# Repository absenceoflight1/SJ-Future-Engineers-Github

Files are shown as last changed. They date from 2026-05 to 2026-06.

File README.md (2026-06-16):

# SJ-Future-Engineers

Welcome to the GitHub Repository of Team Robosenian, competing for the Philippine Robotics Olympiad Future Engineers 2026. The robot is an autonomous, scaled-down vehicle designed to navigate a structured track, avoid obstacles (red and green pillars), and park or change lanes based on visual feedback. The architecture decouples high-level computer vision and path planning from low-level motor actuation and sensor data aggregation.

The autonomous vehicle uses a single SPIKE Prime Large Hub as both the high-level logic controller and low-level actuator driver. The robot navigates an obstacle course using color detection and ultrasonic distance mapping, processing all feedback locally on the hub using the Pybricks.

Steering Mechanism (Ackermann Geometry)
Instead of differential drive (like a tank), the vehicle utilizes Ackermann steering geometry. This ensures that when the robot turns, all wheels trace concentric circles around a single common center point, preventing the tires from slipping sideways.
Actuation: A single spike prime motor is linked to the front steering knuckles via adjustable turnbuckles.
Mechanical Advantage: The steering linkages are configured so that the inner wheel turns at a sharper angle than the outbound wheel during a turn.
Propulsion: A single SPIKE Large Motor drives the rear axle.
Color Sensors: Mounted low to the ground, pointing down at the front to recognize boundary lines (blue/orange), or angled forward to evaluate the color signatures of obstacle pillars (red/green). 
Ultrasonic Sensor: Mounted to the side and front to identify track outer walls or confirm distance to a pillar.

# Members 
-**<p>Ethan Blaire S. De la Piña</p>** 
*<p>Background: Student of San Jose National High School</p>*
<p>Role: Coder, Strategist</p>
Year of Birth: 2009

-**<p>Jay Arnel A. Garcia</p>**
*<p>Background: Student of San Jose National High School</p>*
Role: 3D Printer, Documentator
<p>Year of Birth: 2010</p>

-**<p>Mel Iven M. Pangandoyon</p>**
*<p>Background: Student of San Jose National High School</p>*
Role: Build Designer, Coder
<p>Year of Birth: 2009</p>

-**<p>Nelson T. Ingking</p>**
*<p>Background: Teacher in San Jose National High School</p>*
Role: Team Coach, Guide
<p>Year of Birth: 1985</p>

# Strategies

The strategy we implemented for Open Challenge is that, after the color sensor first detects whether it is orange or blue, it accelerates based on the direction it is moving. For the Obstacle Challenge, our strategy is that after the color sensor detects a line, whether orange or blue, the robot maneuvers itself into the direction it will run, parallel to the wall.

### Mobility Management 

Mobility management governs how our vehicle physically moves, translates software decisions into mechanical force, and maintains structural stability on the track. Our architecture decouples traction control (propulsion) from directional control (steering) to optimize efficiency, torque, and tracking accuracy.
<p>A. Propulsion System (The Drive Motor)Component Selected: SPIKE Large Motor (drive = Motor(Port.C))</p>
<p>Implementation: Mounted longitudinally at the rear of the vehicle, driving the rear axle directly.</p>
<p>Engineering Principles (Torque vs. Speed): The propulsion system requires high starting torque to overcome static friction and rapidly accelerate out of corner turns. The Large Motor provides a superior stall torque (continuous, peaking higher under duty cycle) compared to smaller variants. Because our script commands the motor using raw duty cycle percentages (drive.dc(DCSPEED)), the motor naturally draws more current to provide the necessary torque when encountering resistance, maintaining steady momentum without stalling.</p>
<p>B. Directional Control (The Steering Actuator)Component Selected: SPIKE Medium Servo Motor (steer = Motor(Port.A))</p>
Implementation: Positioned at the front of the vehicle, directly over the front axle assembly.</p>
<p>Engineering Principles (Precision & Speed): Steering requires high rotational speed and precise angular positioning rather than high continuous torque. The Medium Servo features a lower internal gear ratio, allowing it to snap to exact targeted angles (steer.run_target(1000, angle)) at speeds up to 1000 deg/s.</p>
<p>Internal PID Feedback: Both motors utilize embedded optical encoders that track positions with 1 degree resolution. This allows the Pybricks firmware to run internal Proportional-Integral-Derivative (PID) loops, ensuring the steering angles match our software's structural variables precisely, even under the lateral stress of a turn.</p>
Vehicle Chassis Design and Geometry. The foundation of our mobility management relies on Ackermann Steering Geometry rather than a differential (tank-style) drive.</p>

**<p>3D PRINTED FILES</p>**
[BASE](models/FE_NEW_BASE.stl)
[L HOLDER](models/NEW_FE_LHOLDERR.stl)
[COVER](models/cover.stl)
[ULTRASONICHOLDER](models/newsonicholder.stl)
### Power and Sense Management

<p>Power and sense management dictate how our vehicle distributes electrical energy to sustain high-performance operations and how it gathers environmental telemetry to safely solve the track challenges. This subsystem ensures that our computational nodes, sensors, and actuators are adequately powered without experiencing voltage drops or signal degradation.</p>

**<p>A. Primary Power: LEGO SPIKE Prime Battery</p>**
<p><strong>Specifications: 7.3V, 21000 mAh</strong>Lithium-Ion rechargeable battery pack housed inside the SPIKE Prime Hub.</p>
<p><strong>Allocation:</strong>Powers the central ARM Cortex-M7 processor, the internal 6-axis IMU, the front steering servo motor, the rear drive motor, the downward color sensor, and the ultrasonic sensor.</p>
<p><strong>Engineering Justification:</strong>The drive motor experiences heavy spikes in inductive current draw during acceleration and rapid reversals. By keeping this high-current draw on its own isolated chemical cell, we eliminate the risk of voltage sags (brownouts) that would reset our microcontrollers.</p>

**<p>B. Secondary Power: Vinko Mini Fast-Charging Power Bank</p>**
<p><strong>Specifications: 10000mAh (or 20000mAh)</strong>capacity featuring built-in smart LED capacity tracking and an integrated Type-C braided cable delivering up to <strong>22.5W max</strong> output power.</p>
<p><strong>Allocation:</strong> Dedicated solely to powering our co-processing vision subsystem: the ESP32 microcontroller and the DFRobot HuskyLens AI camera.</p>

### Open Challenge
Objective: Complete three autonomous laps.

The first problem we experienced was the random internal wall placements. The solution we implemented is that we put ultrasonics on both sides(left and right) of the robot. Another problem was the inconsistent reading of the color sensor. The solution we made was to make sure the sensor's physical environment is stable and maintain a consistent height. The last problem we encountered was that sometimes the build would fall off on its own. The solution for that was to balance the weight distribution of the robot.

### Open Management
Open Challenge management governs how our vehicle navigates a completely clear, obstacle-free track. In this mode, the primary objective is maximizing speed, minimizing lap times, and executing mathematically perfect 90° turns. The strategy focuses heavily on deep sensor synchronization, using the ground color sensor to locate boundary lines and the internal Inertial Measurement Unit (IMU) to lock down straight trajectories.

**Straight-Line Navigation (PD Gyro Control)**
<p>To prevent the vehicle from drifting into track walls over long straightaways, we implemented a Proportional-Derivative (PD) Gyro Control loop inside the do_gyro() function.</p>
<p>The vehicle constantly calculates its heading error by comparing its current absolute compass heading against our software's directional target variable (target).</p>

```python
err  = hub.imu.heading() - target
rate = hub.imu.angular_velocity()[2]
cor  = max(-STEER_LIMIT, min(STEER_LIMIT, KP * err - KR * rate))
steer.run_target(1000, int(STEER_CENTER + cor), wait=False)

```

<p>Proportional Control (KP * err): Quantifies how far off course the vehicle has drifted. We set KP to 3.0, meaning if the car drifts 5° to the left, the steering servo instantly counters by turning the front wheels 15° to the right.</p>

<p>Derivative Control (KR * rate): Measures the vehicle's rotational velocity (how fast it is spinning). We set KR to 0.2. This acts as an automated shock absorber, dampening the steering adjustments as the car approaches its straight heading to prevent erratic fish-tailing or over-correction.</p>

<p>Saturation Guarding: The final correction factor (cor) is bound tightly by STEER_LIMIT (80°) to prevent the code from forcing the motor past its physical end-stops.</p>

**Automated Cornering Strategy (The Race Line)**
<p>The vehicle tracks its progress around the course by using its downward-facing color sensor to recognize bright boundary lines taped to the track floor. When a line is crossed, the car executes a multi-stage turning matrix:</p>

*<p>Stage 1: Line Verification and Race Calibration</p>*
<p>The ground sensor reads the floor data. The functions is_blue() and is_orange() monitor Hue, Saturation, Value, and Reflection simultaneously. Once a line is confirmed, the vehicle ignores all subsequent color changes for a set duration (COOLDOWN_MS = 10000) to guarantee that the same physical line isn't counted twice.</p>

*<p>Stage 2: Frontal Distance Cushioning</p>*
<p>Upon registering a line, the vehicle does not turn immediately. It triggers wait_for_wall(), maintaining its straight gyro line at a controlled DCSPEED (50%) until the front ultrasonic sensor confirms that the vehicle is within 100 mm(WALL_TURN_MM) of the corner wall. This ensures the vehicle maximizes its deep entry into the corner before breaking away.</p>

*<p>Stage 3: Gyro Target Re-mapping</p>
<p>Once the spatial cushion is met, the code modifies our global absolute reference frame by precisely 90°:</p>

```python
if tdir == 'blue':
    target -= 90      # Adjust heading target for a sharp Left Turn
    direction = 1
else:
    target += 90      # Adjust heading target for a sharp Right Turn
    direction = 2

```

*<p>Stage 4: High-Torque Pivot Reversal</p>
<p>The vehicle cranks its front steering servo completely to its outer edge (TURN_STEER = 80). The main loop is temporarily suspended, and the rear drive motor runs in high-velocity reverse power (drive.run(-600)).</p>
<p>The vehicle swings its rear end around, pivoting into the corner. The internal IMU samples the rotation at a hardware level. The moment the gyro sensor registers that the vehicle's body has aligned within a tight 5° tolerance window (GYRO_ALIGN_TOL) of our new target heading, the reverse power cuts out, the steering assembly straightens back to 0°, </p>

### Obstacle Challenge 
Objective: Complete three laps with a traffic sign aligned with its direction.

The first problem we experienced was fixing the traffic sign compliance. The solution for that was to put a Husky Lens Camera that can be connected to an LMS. The second was the inconsistent detection of traffic lights from the camera. The solution was to put the camera at the back for a wider field of view. We also implemented a gyro for precise straight movement, maintaining angular velocity, and allowing a robot to track its rotation.

### Obstacle Management

Obstacle management defines how our vehicle identifies, evaluates, and evades hazards on the track in real time. For SJ-Future-Engineers, this system is divided into two distinct protective layers: Computer Vision Pillar Evasion (high-level path modifications handled via the camera) and the Ultrasonic Collision Buffer (low-level emergency braking handled via acoustic ranging).

High-Level Obstacle Evasion (The AI Vision Pipeline)
The primary tool for managing colored pillars (red and green blocks) is our machine learning co-processing subsystem, which is the LMS.

<p>A. Target Classification and Filtering.</p> 
<p>The HuskyLens camera constantly streams a 6-integer telemetry array to the SPIKE Prime Hub. The hub instantly processes these variables through a series of logical validation steps:</p>
<p>Color Identification: The function classify_block() translates the camera's raw signature ID (cid) into descriptive 'green' or 'red' text strings.</p>
<p>Dual-Target Arbitration: If both a red and a green pillar appear in the frame simultaneously, the main execution loop compares their bounding-box widths (green_w and red_w). The program prioritizes whichever block has the larger width, as a wider pixel profile indicates it is physically closer and poses the immediate structural threat.</p>
<p>Lock Acquisition: Once a dominant block is identified within a critical distance boundary (block_y > 50), the system triggers a software lock (locked_block). This lock prevents the car from switching target strategies midway through a turn if a second color flashes into view.</p>
<p>B. Spatial Zoning Matrices</p>
<p>The script partitions the camera’s 320 x 240 pixel viewing window into a coordinate grid to evaluate threats:</p>
<p>The X-Axis (Horizontal Positioning): Evaluated by classify_block_x(). It maps where the obstacle sits relative to our centerline.</p>
<p>The Y-Axis (Proximity Depth): Evaluated by classify_block_y(). A value of cy > 50 indicates the vehicle has breached the safe approach threshold.</p>
<p>The Width Profile (Size Verification): Evaluated by classify_block_width(). A pixel width value of cw >=11 triggers an "emergency" classification, proving the object is an actual roadblock and not a distant background color glitch.</p>

**<p>C. Evasion Trajectory Execution</p>**
<p>When detect_block() reports that a block is "near" and its size is an "emergency", the vehicle breaks away from its straight gyro line and enters the turn_to_ok() evasion routing:</p>

```python
if block_color == 'green':
    ok_zone    = 'g_kinda_ok'  # Safe escape corridor (cx: 64-128)
    wiggle_dir = 25            # Hard steer right
else:
    ok_zone    = 'r_kinda_ok'  # Safe escape corridor (cx: 64-128)
    wiggle_dir = -25           # Hard steer left

```
The vehicle suspends its standard gyro tracking algorithm and turns its steering knuckles exactly $25^\circ$ in the opposite direction of the block's identity—steering right to clear green pillars and steering **left to clear red pillars**.
<p>The car maintains this evasive curve until the camera feed updates and confirms that the block's horizontal coordinate (bx) has shifted completely into the safe peripheral flank zone (ok_zone). Once cleared, the wheel center, old tracking flags reset, and the background gyro control takes back control of straight-line navigation.</p>

**<p>3.3 Low-Level Collision Buffering (The Ultrasonic Safety Net)</p>**
<p>If an obstacle is missed by the camera (due to extreme glare, dark shadows, or an unlearned color profile), or if the vehicle approaches a solid track wall head-on, our low-level sensor array takes over.</p>
<p>The front-facing ultrasonic sensor (ultra) acts as an automated safety brake. It measures the physical distance to objects directly ahead by bouncing high-frequency sound waves off surfaces.</p>

```python 
if brake_on and df < ULTRA_FRONT_MM:
    emergency_reverse()

```
                     
<p>If the distance to a solid surface drops below 50 mm (ULTRA_FRONT_MM), the program stops processing normal track loops and fires emergency_reverse(). This routine drops the propulsion system into reverse power (-600) and backs up for exactly 1000 ms while centering the steering mechanism. This creates a spatial cushion, allowing the vehicle to reset its orientation and avoid an impact that could damage its front chassis or steering linkage geometry.</p>

# Modules

pybricks.hubs (PrimeHub): The core library for the main vehicle controller. It manages internal electronics like the 6-axis Inertial Measurement Unit (IMU/Gyro), built-in speaker, status LED matrix, and battery management.

pybricks.pupdevices (Motor, ColorSensor, UltrasonicSensor): The hardware abstraction layer for LEGO Powered Up (PUP) peripherals. It contains built-in feedback control systems (PID loops), allowing the code to command precise angles, tracking speeds, and distances.

pybricks.parameters (Color, Port): A configuration module containing constants that define the physical layout of the hub (e.g., ports A through E) and primitive colors for the LED light.

pybricks.tools (wait, StopWatch): The time-management module. wait() yields CPU control for safe scheduling, while StopWatch() implements software timers used heavily in your code for cooldowns and emergency reverse durations.

pupremote_hub (PUPRemoteHub): A communication protocol module. It enables the LEGO Hub to communicate via UART serial communication over a standard sensor port to an external microcontroller (in your case, an ESP32 running a HuskyLens AI camera).
### Electromechanical Hardware Mapping

| Component Instance | Physical Hardware Component | Vehicle Subsystem | Software Interaction & Functionality |
| :--- | :--- | :--- | :--- |
| **`hub = PrimeHub()`** | LEGO SPIKE Prime Brick / Hub | Central Controller & IMU | Processing unit. Uses internal **6-axis Gyro** via `hub.imu.heading()` to keep the vehicle straight. Controls built-in status lights and speaker beeps. |
| **`steer = Motor(Port.A)`** | LEGO Powered Up Servo Motor | Steering Actuator | Connected to front wheels. Uses internal optical encoders to turn wheels to exact structural angles (`STEER_CENTER`, `SIDE_WALL_NUDGE_STEER`). |
| **`drive = Motor(Port.C)`** | LEGO Powered Up Large Motor | Propulsion System | Connected to drive axles. Commanded via direct motor power duty-cycles (`drive.dc(DCSPEED)`) or regulated velocity track speeds (`drive.run()`). |
| **`color = ColorSensor(Port.E)`** | LEGO Color Sensor | Downward Lap Sensor | Pointed at track floor. Measures Hue, Saturation, Value, and raw reflection variables to flag down-track Blue/Orange boundary lap lines. |
| **`ultra = UltrasonicSensor(Port.D)`** | LEGO Ultrasonic Distance Sensor | Front Collision Buffer | Emits acoustic sound waves straight ahead. Evaluates buffer zone distance (`front_dist()`). Triggers emergency braking routines if wall distance drops below 50mm. |
| **`lms = PUPRemoteHub(Port.B)`** | ESP32 MCU + HuskyLens AI Camera | Vision & Side-Telemetry | Communicates via a serial UART bridge. Translates object bounding boxes (`cx`, `cy`, `cw`) and side-wall ToF sensor distances into raw system data arrays. |

### The Process to Build, Compile, and Upload the Code

We ensure that our LEGO Prime Hub has the  Pybricks Firmware installed. We have a Pybricks Code installed on our laptops. With this, we can now upload our code to the SPIKE Prime Hub and have the robot complete the open and obstacle challenges. When we click the green Play icon inside the Pybricks IDE, the deployment pipeline executes an automated process instantly. First, the browser IDE handles syntactic verification by parsing our code to catch structural Python syntax errors or unmapped variables before deployment. Next, bytecode compilation takes over to instantly compress the raw MicroPython script into an optimized, lightweight binary representation called a .mpy file. Finally, a stream upload sends this compiled bytecode directly over our active Bluetooth Low Energy or USB-C connection into the volatile RAM of the LEGO Prime Hub controller, initializing the vehicle for immediate execution.

# Pictures -Team and vehicle 

### Team Photos

**<p>Fun Photo</p>**

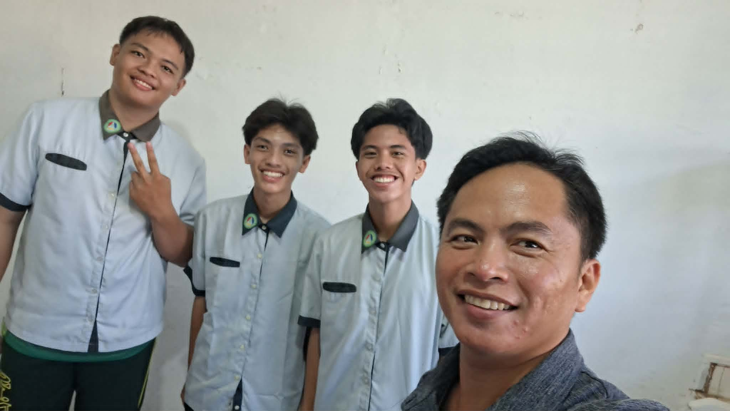
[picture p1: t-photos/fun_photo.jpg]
Fun Photo


**<p>Team Photo</p>**

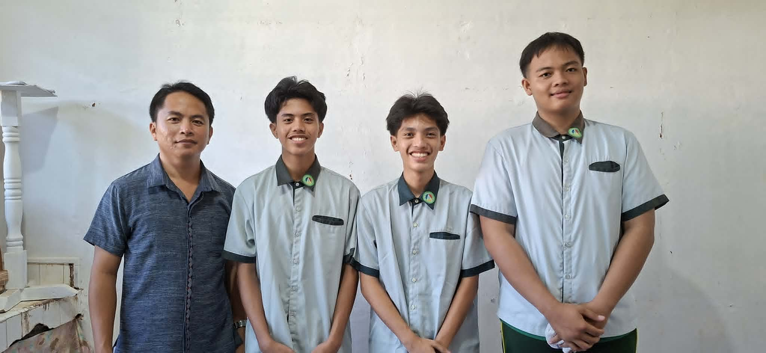
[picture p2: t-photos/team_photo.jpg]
Team Photo


<p>Official Team Photo</p>

### Vehicle Photos

**<p>Bottom View</p>**

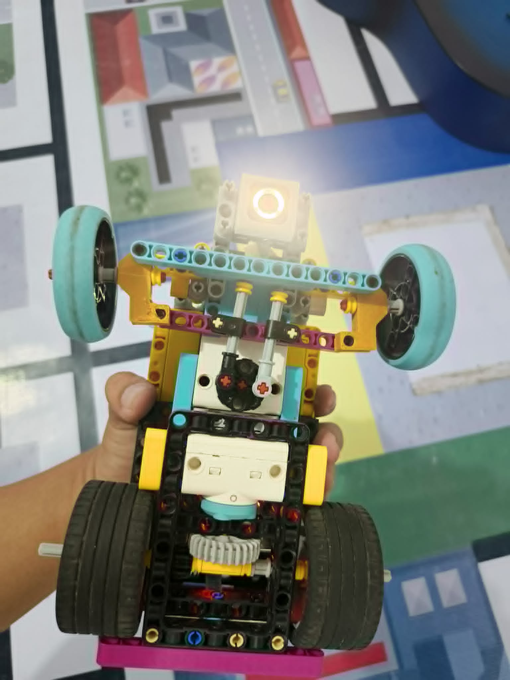
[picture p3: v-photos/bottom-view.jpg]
Bottom View


**<p>Front View</p>**

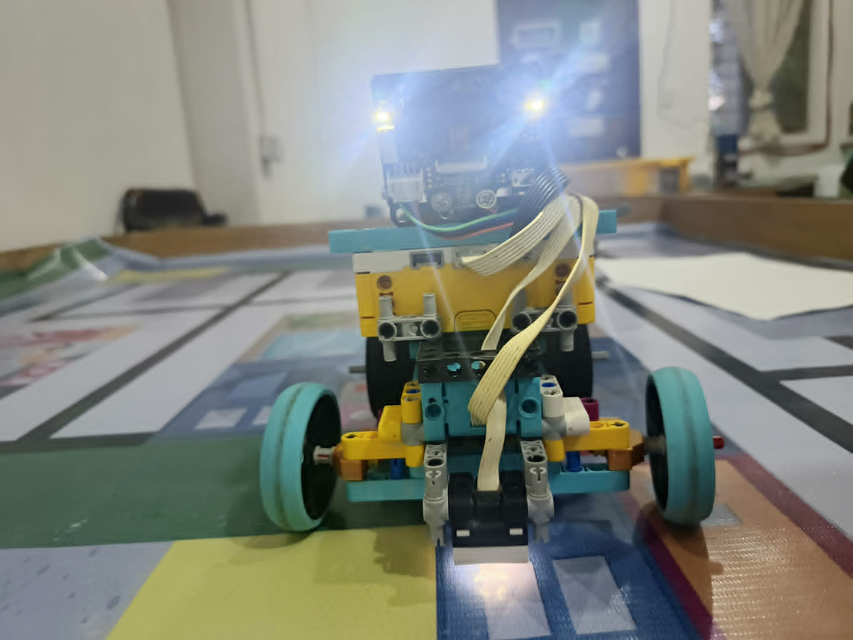
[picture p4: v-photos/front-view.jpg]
Front View


**<p>Left View</p>**

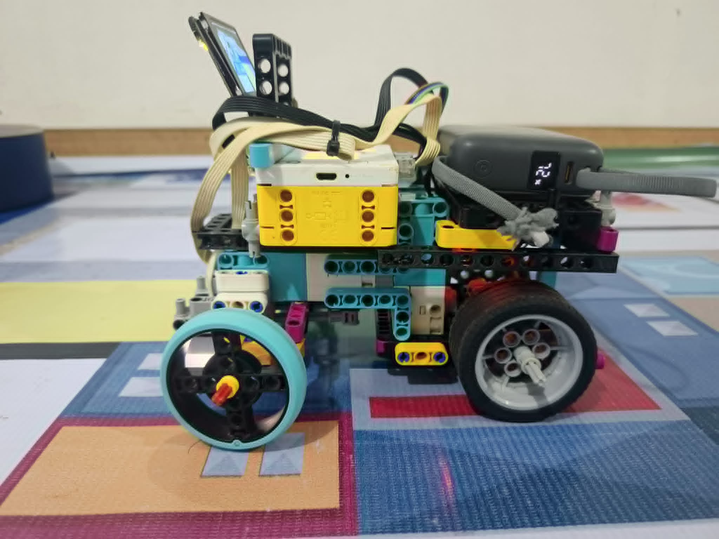
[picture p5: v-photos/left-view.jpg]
Left View


**<p>Rear View</p>**

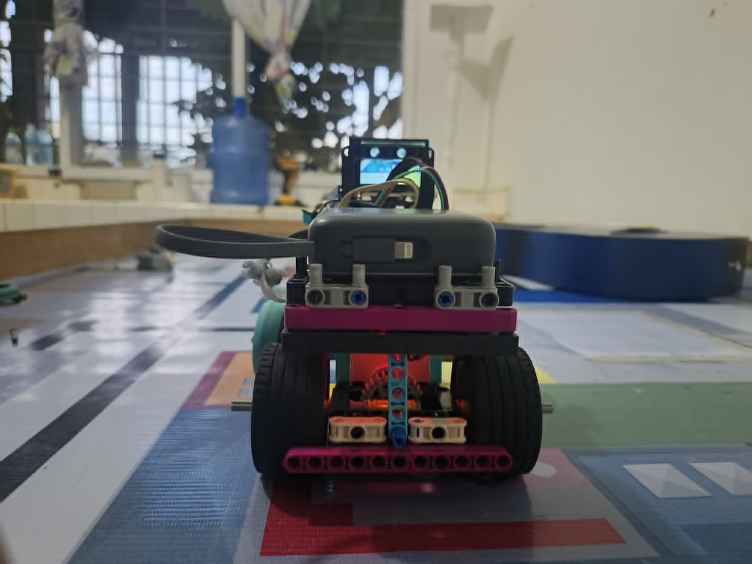
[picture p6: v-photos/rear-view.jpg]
Rear View


**<p>Right View</p>**

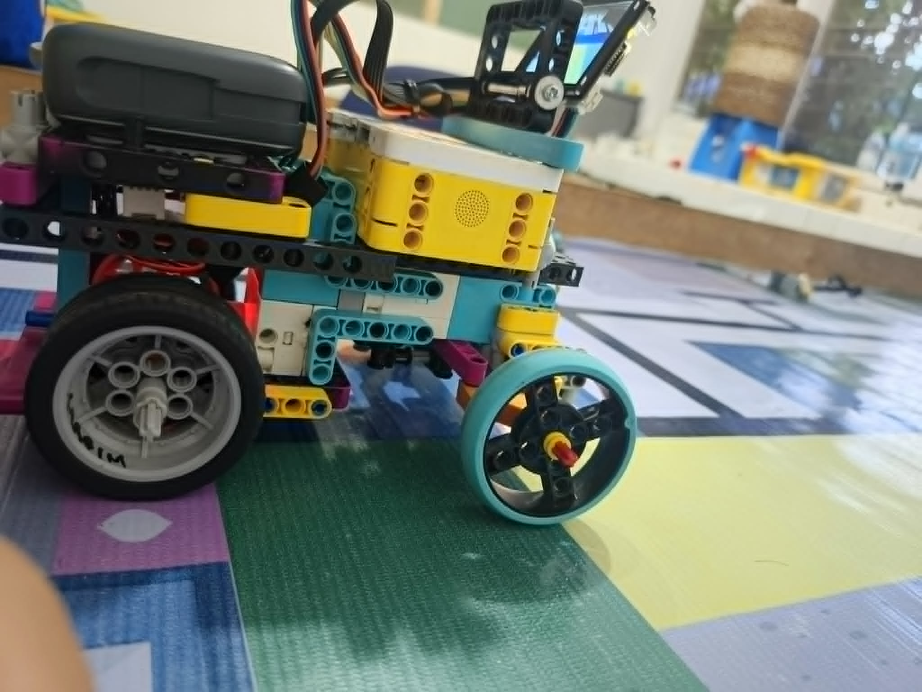
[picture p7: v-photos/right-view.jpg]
Right View


**<p>Top View</p>**

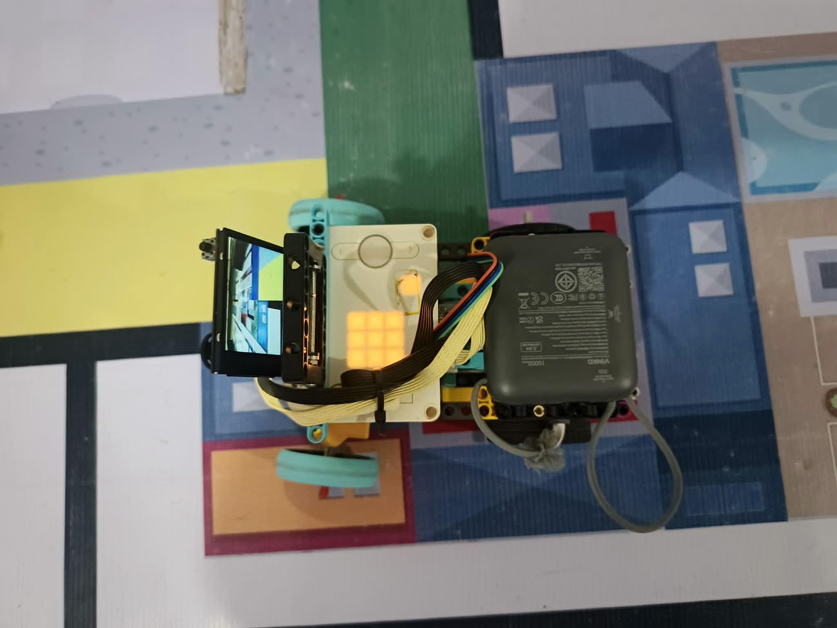
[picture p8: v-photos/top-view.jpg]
Top View


More description on 't-photos' subfolder.

# Video

**<p>Videos</p>**

Open Challenge Video (https://youtu.be/iB-URkR1FVM)

<a href="https://www.youtube.com/watch?v=iB-URkR1FVM">Youtube Link</a>

-<strong>Obstacle Challenge</strong>
    Obstacle Challenge Video (https://youtu.be/drb0f370XIs)

<a href="https://www.youtube.com/watch?v=drb0f370XIs">Youtube Link</a>

YouTube links are accessible. For more information, please look at the video subfolder.

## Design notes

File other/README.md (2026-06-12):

# Materials Used

<strong>LMS</strong>
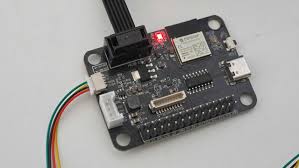
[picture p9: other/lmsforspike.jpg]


We used LMS to connect the Servo Motor and Husky Lens Camera to SPIKE.

<strong>Husky Lens Camera</strong>
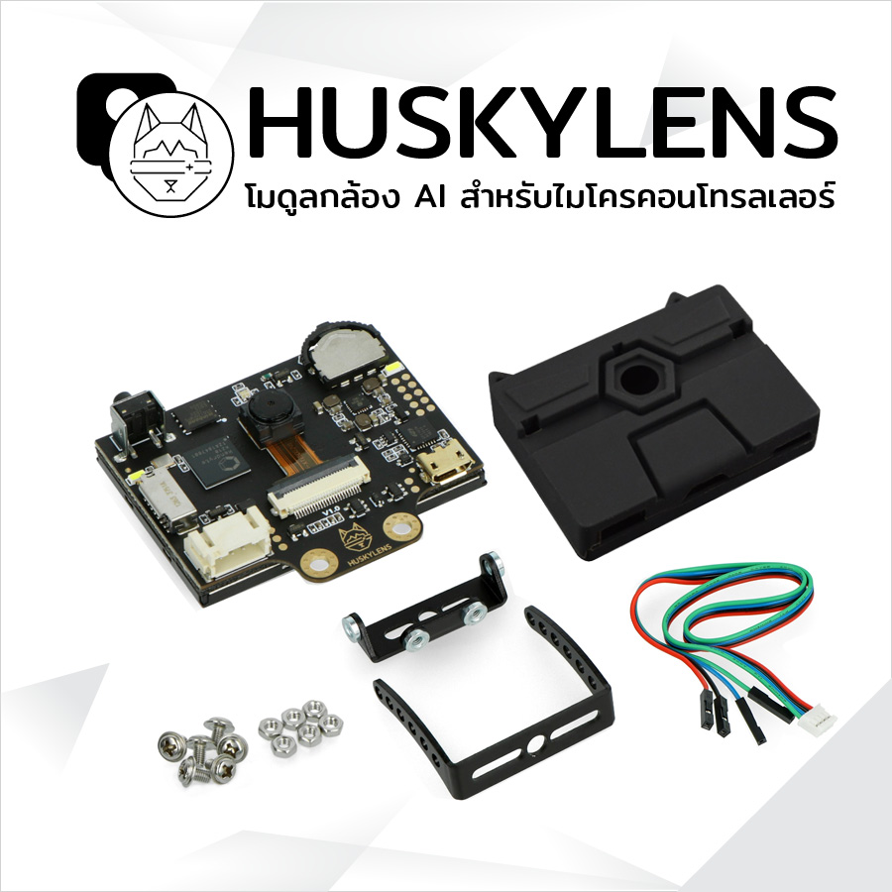
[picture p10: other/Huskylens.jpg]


A camera used to detect blocks and their color.

<strong>Servo Motor</strong>
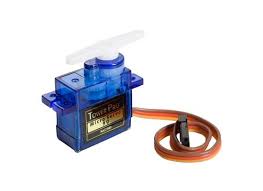
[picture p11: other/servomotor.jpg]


The servo motor is used for moving the camera left and right.

<strong> Power Bank </strong>
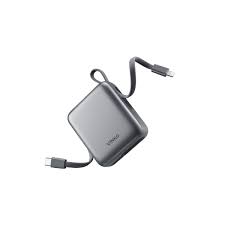
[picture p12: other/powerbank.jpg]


The main power supply, used to provide voltage for the robot.

All other materials are from LEGO Education Spike.

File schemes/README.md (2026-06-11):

Electromechanical diagrams
====

This directory contains schematic diagrams.

This is the hand-drawn schematic diagram for LMS.

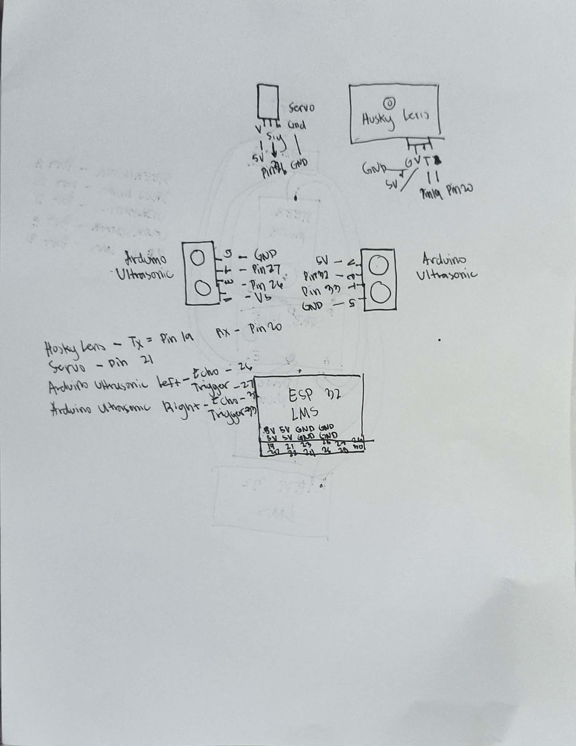
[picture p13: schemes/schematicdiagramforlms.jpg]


This is the hand-drawn schematic diagram for Spike.

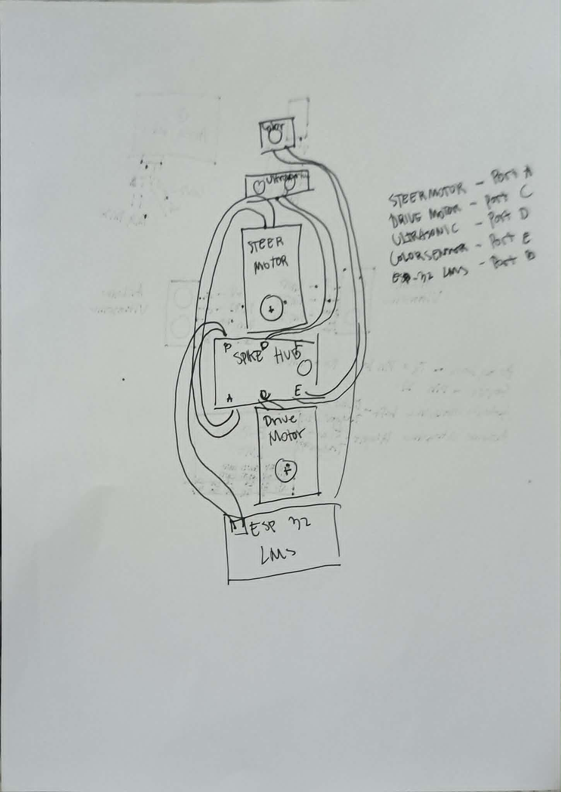
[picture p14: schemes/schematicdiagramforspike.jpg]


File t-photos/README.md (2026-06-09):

Team's photos
====
This is our team photo. 



This is our fun photo.


Fun fact: We were thinking about what pose we would use, but suddenly our teacher took his phone and snapped a photo of us while brainstorming. So, the three of us just looked at the camera and smiled.

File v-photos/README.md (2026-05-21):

Vehicle's photos
====

This directory showcases the full model of our autonomous driving car. Each photo consists of every angle from top, right, rear, left, front, and bottom.

### Top View - `top-view.jpg`

Top View

### Bottom View - `bottom-view.jpg`

Bottom View

### Front View - `front-view.jpg`

Front View

### Rear View - `rear-view.jpg`

Rear View

### Right View - `right-view.jpg`

Right View

### Left View - `left-view.jpg`

Left View

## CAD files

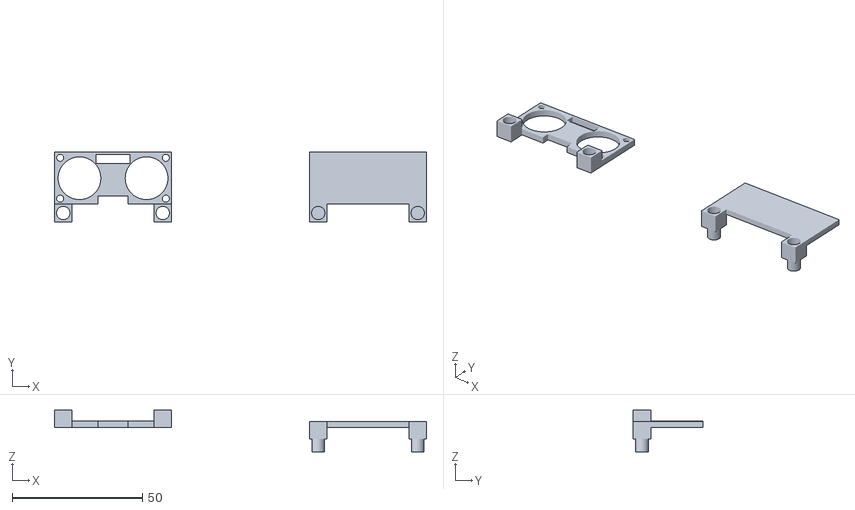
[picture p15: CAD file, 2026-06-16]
models/newsonicholder.stl
143.0 x 26.8 x 16.0

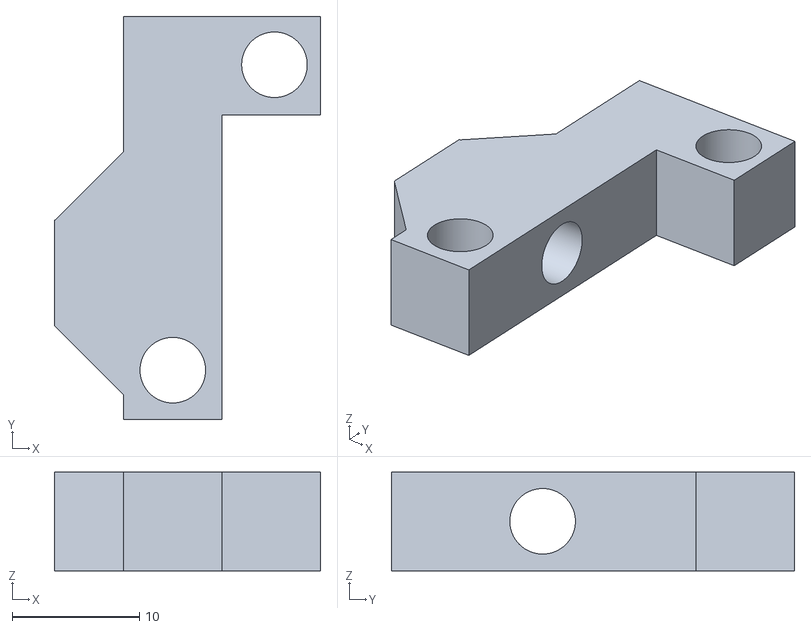
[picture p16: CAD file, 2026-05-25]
models/NEW_FE_LHOLDERR.stl
20.9 x 31.7 x 7.75

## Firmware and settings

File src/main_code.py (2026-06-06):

from pybricks.hubs import PrimeHub
from pybricks.pupdevices import Motor, ColorSensor, UltrasonicSensor
from pybricks.parameters import Color, Port
from pybricks.tools import wait, StopWatch
from pupremote_hub import PUPRemoteHub

hub   = PrimeHub()
steer = Motor(Port.A)
drive = Motor(Port.C)
color = ColorSensor(Port.E)
ultra = UltrasonicSensor(Port.D)

drive.control.limits(acceleration=20000)
steer.control.limits(acceleration=20000)

# speeds
SPEED       = 40
SPEED_FAST  = 100

# gyro
KP = 2.0
KR = 0.3
STEER_CENTER = 0
STEER_LIMIT  = 60

# turns
TURN_STEER        = 60
TURN_DEGREES      = 160
TURN_STEER_FAST   = 55
TURN_DEGREES_FAST = 155

# laps
TOTAL_LAPS    = 3
LINES_TO_STOP = TOTAL_LAPS * 4
COOLDOWN_MS   = 1500

# color thresholds (HSV)
BLUE_H_MIN = 205;  BLUE_H_MAX = 230
BLUE_S_MIN = 65;   BLUE_S_MAX = 95
BLUE_V_MIN = 35;   BLUE_V_MAX = 65
BLUE_REF_MIN = 15; BLUE_REF_MAX = 35

ORANGE_H_MIN = 335; ORANGE_H_MAX = 15
ORANGE_S_MIN = 35;  ORANGE_S_MAX = 80
ORANGE_V_MIN = 45;  ORANGE_V_MAX = 80
ORANGE_REF_MIN = 25; ORANGE_REF_MAX = 50

# camera / obstacle
CAM_MIN_WIDTH      = 30
CAM_HEADING_OFFSET = 30
HOLD_TIME          = 800
RETURN_TIME        = 800

# front ultrasonic (obstacle mode only)
ULTRA_FRONT_MM   = 120
ULTRA_REVERSE_MS = 1500
REV_STEER_RED    =  50
REV_STEER_GREEN  = -50
COUNTER_MS       = 400

# wall following (fast mode only)
WALL_MIN_MM   = 120
WALL_KP       = 0.06
WALL_MAX_OFF  = 12
WALL_VALID_MM = 500

# soft wall nudge (obstacle mode only)
OBS_WALL_MIN_MM  = 150
OBS_WALL_MAX_OFF = 8

# inner sweep (obstacle mode only)
SWEEP_OFFSET  = 12
SWEEP_DIST_MM = 80
SWEEP_SPEED   = 40

# parking exit
PARK_FWD_STEER   = -40
PARK_FWD_SPEED   = 80
PARK_FWD_MS      = 1100
PARK_STRAIGHTEN  = 30
PARK_REV_SPEED   = 85
PARK_REV_MS      = 700
PARK_STEER_OUT   = -35
PARK_OUT_SPEED   = 100
PARK_OUT_MS      = 1300
PARK_ALIGN_STEER = 40
PARK_ALIGN_SPEED = 90
PARK_ALIGN_MS_RIGHT = 2500
PARK_ALIGN_MS_LEFT  = 2000

# parallel parking
PARALLEL_SPEED        = 50
PARALLEL_STEER_SHARP  = 60
PARALLEL_STEER_CENTER = 0

# spike detection
PARK_SPIKE_THRESHOLD  = 150
PARK_BASELINE_SAMPLES = 5
PARK_DETECT_SPEED     = 30

# mode detection threshold
WALL_DETECT_MM = 300

# avoid states
AVOID_NONE      = 0
AVOID_ACTIVE    = 1
AVOID_RETURNING = 2
AVOID_HOLDING   = 3

# state vars
target      = 0
direction   = 0
lap_lines   = 0
on_line     = False
avoid_off   = 0
avoid_state = AVOID_NONE
avoid_dir   = 0
wall_off    = 0
gyro_on     = False
brake_on    = False
fast_mode   = False
turn_pend   = None

wf_dl      = [9999, 9999, 9999]
wf_dr      = [9999, 9999, 9999]
wf_dl_last = 9999
wf_dr_last = 9999

hold_tmr     = StopWatch()
return_tmr   = StopWatch()
cooldown_tmr = StopWatch()

# boot
steer.run_target(1000, 0)
hub.light.on(Color.YELLOW)
print("booting...")
wait(2000)
hub.imu.reset_heading(0)
wait(300)
if abs(hub.imu.heading()) > 2:
    hub.imu.reset_heading(0)
    wait(300)

print("starting ESP32...")
lms = PUPRemoteHub(Port.B)
lms.add_channel('hl', 'hhhhhh')
wait(1500)

dl_samples = []
dr_samples = []
for _ in range(3):
    try:
        _, _, _, _, dl, dr = lms.call('hl')
        if dl > 0: dl_samples.append(dl)
        if dr > 0: dr_samples.append(dr)
    except:
        pass
    wait(200)

try:
    df = ultra.distance()
    if df is None: df = 9999
except:
    df = 9999

dl = min(dl_samples) if dl_samples else 9999
dr = min(dr_samples) if dr_samples else 9999

print("boot dist  F:", df, "L:", dl, "R:", dr)

close = 0
if df <= WALL_DETECT_MM: close += 1
if dl <= WALL_DETECT_MM: close += 1
if dr <= WALL_DETECT_MM: close += 1

both_sides = dl <= WALL_DETECT_MM and dr <= WALL_DETECT_MM

if close >= 2 or both_sides:
    fast_mode = False
    hub.light.on(Color.RED)
    hub.speaker.beep(frequency=800, duration=200)
    print("obstacle mode  close sensors:", close)
else:
    fast_mode = True
    hub.light.on(Color.WHITE)
    hub.speaker.beep(frequency=1500, duration=150)
    hub.speaker.beep(frequency=1800, duration=150)
    print("fast mode  close sensors:", close)

print("ready  laps:", TOTAL_LAPS, " lines:", LINES_TO_STOP)
hub.light.on(Color.GREEN)
hub.speaker.beep(1000, 100)
hub.speaker.beep(1200, 100)

# ── helpers ──────────────────────────────────────────────────────────────────

def spd():
    return SPEED_FAST if fast_mode else SPEED

def t_steer():
    return TURN_STEER_FAST if fast_mode else TURN_STEER

def t_deg():
    return TURN_DEGREES_FAST if fast_mode else TURN_DEGREES

def do_gyro():
    if not gyro_on:
        return
    err  = hub.imu.heading() - (target + avoid_off + wall_off)
    rate = hub.imu.angular_velocity()[2]
    cor  = max(-STEER_LIMIT, min(STEER_LIMIT, KP * err - KR * rate))
    steer.run_target(1000, int(STEER_CENTER + cor), wait=False)

def front_dist():
    try:
        d = ultra.distance()
        return d if d else 9999
    except:
        return 9999

def read_cam():
    try:
        cx, cy, cw, cid, dl, dr = lms.call('hl')
        return cx, cw, cid, (dl if dl > 0 else 9999), (dr if dr > 0 else 9999)
    except:
        return 0, 0, 0, 9999, 9999

def wall_follow(dl, dr):
    global wall_off, wf_dl, wf_dr, wf_dl_last, wf_dr_last
    wall_off = 0

    if not gyro_on or turn_pend or direction == 0:
        return

    if fast_mode:
        wf_dl = [wf_dl[1], wf_dl[2], dl]
        wf_dr = [wf_dr[1], wf_dr[2], dr]

        def med(a, b, c):
            if a > b: a, b = b, a
            if b > c: b, c = c, b
            if a > b: a, b = b, a
            return b

        dlf = med(*wf_dl)
        drf = med(*wf_dr)

        if dlf < 9999: wf_dl_last = dlf
        else:          dlf = wf_dl_last
        if drf < 9999: wf_dr_last = drf
        else:          drf = wf_dr_last

        dl_ok = dlf < WALL_VALID_MM
        dr_ok = drf < WALL_VALID_MM

        if dl_ok and dlf < WALL_MIN_MM:
            wall_off = WALL_MAX_OFF
            return
        if dr_ok and drf < WALL_MIN_MM:
            wall_off = -WALL_MAX_OFF
            return

        if dl_ok and dr_ok:
            wall_off = max(-WALL_MAX_OFF, min(WALL_MAX_OFF, (drf - dlf) * WALL_KP))
        elif dl_ok and dlf < WALL_MIN_MM * 1.5:
            wall_off =  WALL_MAX_OFF // 2
        elif dr_ok and drf < WALL_MIN_MM * 1.5:
            wall_off = -(WALL_MAX_OFF // 2)

    else:
        dl_live = dl if dl > 0 else 9999
        dr_live = dr if dr > 0 else 9999

        if dl_live < OBS_WALL_MIN_MM:
            wall_off = OBS_WALL_MAX_OFF
        elif dr_live < OBS_WALL_MIN_MM:
            wall_off = -OBS_WALL_MAX_OFF

def is_blue(h, s, v, ref):
    return BLUE_H_MIN <= h <= BLUE_H_MAX \
       and BLUE_S_MIN <= s <= BLUE_S_MAX \
       and BLUE_V_MIN <= v <= BLUE_V_MAX \
       and BLUE_REF_MIN <= ref <= BLUE_REF_MAX

def is_orange(h, s, v, ref):
    return (h >= ORANGE_H_MIN or h <= ORANGE_H_MAX) \
       and ORANGE_S_MIN <= s <= ORANGE_S_MAX \
       and ORANGE_V_MIN <= v <= ORANGE_V_MAX \
       and ORANGE_REF_MIN <= ref <= ORANGE_REF_MAX

def emergency_stop():
    print("EMERGENCY BRAKE")
    hub.light.on(Color.RED)
    drive.brake()
    steer.run_target(500, 0)
    wait(300)

    _, cw, cid, _, _ = read_cam()
    if cid == 1:   rs = REV_STEER_RED
    elif cid == 2: rs = REV_STEER_GREEN
    else:          rs = 0

    t = StopWatch()
    while t.time() < ULTRA_REVERSE_MS:
        steer.run_target(500, rs, wait=False)
        drive.dc(-spd())
        wait(10)
    drive.brake()
    wait(100)

    if rs != 0:
        t2 = StopWatch()
        while t2.time() < COUNTER_MS:
            steer.run_target(500, -rs, wait=False)
            drive.dc(-spd())
            wait(10)
        drive.brake()
        wait(100)

    steer.run_target(500, 0)
    wait(200)
    hub.light.on(Color.GREEN)

def inner_sweep(tdir):
    if fast_mode:
        return
    sdir = -1 if tdir == 'blue' else 1
    deg  = int(SWEEP_DIST_MM * 3.4)

    drive.reset_angle(0)
    while abs(drive.angle()) < deg:
        _, cw, cid, _, _ = read_cam()
        if front_dist() < ULTRA_FRONT_MM and brake_on:
            emergency_stop()
            return
        if cid in (1, 2) and cw >= CAM_MIN_WIDTH:
            break
        err = hub.imu.heading() - (target + SWEEP_OFFSET * sdir)
        cor = max(-STEER_LIMIT, min(STEER_LIMIT, KP * err - KR * hub.imu.angular_velocity()[2]))
        steer.run_target(1000, int(STEER_CENTER + cor), wait=False)
        drive.dc(SWEEP_SPEED)
        wait(10)

    drive.reset_angle(0)
    while abs(drive.angle()) < deg:
        _, cw, cid, _, _ = read_cam()
        if front_dist() < ULTRA_FRONT_MM and brake_on:
            emergency_stop()
            return
        if cid in (1, 2) and cw >= CAM_MIN_WIDTH:
            break
        err = hub.imu.heading() - target
        cor = max(-STEER_LIMIT, min(STEER_LIMIT, KP * err - KR * hub.imu.angular_velocity()[2]))
        steer.run_target(1000, int(STEER_CENTER + cor), wait=False)
        drive.dc(SWEEP_SPEED)
        wait(10)

def parking_exit():
    global brake_on, gyro_on
    print("parking exit...")
    hub.light.on(Color.MAGENTA)

    df = front_dist()
    _, _, _, dl, dr = read_cam()
    fc = df <= WALL_DETECT_MM
    lc = dl <= WALL_DETECT_MM
    rc = dr <= WALL_DETECT_MM
    print("park dist  F:", df, "L:", dl, "R:", dr)

    if fc and rc and not lc:
        side = "LEFT"
        fs, st, so, al, am = -PARK_FWD_STEER, -PARK_STRAIGHTEN, -PARK_STEER_OUT, -PARK_ALIGN_STEER, PARK_ALIGN_MS_LEFT
        hub.light.on(Color.BLUE)
    elif fc and lc and not rc:
        side = "RIGHT"
        fs, st, so, al, am = PARK_FWD_STEER, PARK_STRAIGHTEN, PARK_STEER_OUT, PARK_ALIGN_STEER, PARK_ALIGN_MS_RIGHT
        hub.light.on(Color.ORANGE)
    else:
        side = "RIGHT"
        fs, st, so, al, am = PARK_FWD_STEER, PARK_STRAIGHTEN, PARK_STEER_OUT, PARK_ALIGN_STEER, PARK_ALIGN_MS_RIGHT
        hub.light.on(Color.WHITE)
        print("ambiguous — defaulting right")

    print("exit side:", side)

    steer.run_target(500, fs, wait=False)
    drive.run(PARK_FWD_SPEED)
    wait(PARK_FWD_MS)

    drive.brake()
    wait(100)
    steer.run_target(500, st)
    drive.run(-PARK_REV_SPEED)
    wait(PARK_REV_MS)
    drive.brake()
    wait(100)

    steer.run_target(500, so)
    drive.run(PARK_OUT_SPEED)
    wait(PARK_OUT_MS)

    steer.run_target(500, al, wait=False)
    drive.run(PARK_ALIGN_SPEED)
    wait(am)
    steer.run_target(500, 0)
    drive.brake()

    brake_on = True
    gyro_on  = True
    hub.light.on(Color.GREEN)
    print("parking done, exited", side)

def do_turn(tdir):
    global target, lap_lines, direction, on_line
    global avoid_off, avoid_state, avoid_dir, wall_off, turn_pend

    hub.speaker.beep(500, 100)
    lap_lines  += 1
    turn_pend   = None
    avoid_off   = 0
    avoid_state = AVOID_NONE
    avoid_dir   = 0
    wall_off    = 0

    if tdir == 'blue':
        hub.light.on(Color.BLUE)
        steer.run_target(1000, t_steer(), wait=False)
        target    -= 90
        direction  = 1
    else:
        hub.light.on(Color.ORANGE)
        steer.run_target(1000, -t_steer(), wait=False)
        target    += 90
        direction  = 2

    print("turn", tdir, "| line", lap_lines, "| lap", lap_lines // 4)

    drive.reset_angle(0)
    while abs(drive.angle()) < t_deg():
        drive.dc(spd())
        do_gyro()

    hub.light.on(Color.GREEN)
    on_line = False
    inner_sweep(tdir)

# ── parallel parking (obstacle mode only) ────────────────────────────────────

def parallel_park_right():
    speed = PARALLEL_SPEED
    sharp = PARALLEL_STEER_SHARP

    print("parallel park RIGHT")
    hub.light.on(Color.ORANGE)
    hub.speaker.beep(900, 150)

    steer.run_target(1000, -sharp, wait=False)
    wait(500)
    drive.run(-speed)
    wait(2000)

    drive.brake()
    wait(500)
    steer.run_target(1000, sharp, wait=False)
    wait(500)

    drive.run(speed)
    wait(3000)
    drive.brake()
    wait(500)

    steer.run_target(1000, PARALLEL_STEER_CENTER, wait=False)
    wait(3000)
    drive.run(-speed)
    wait(4000)
    drive.brake()
    wait(500)

    steer.run_target(1000, sharp, wait=False)
    wait(1000)
    drive.run(-speed)
    wait(2500)
    drive.brake()
    wait(500)

    steer.run_target(1000, -sharp, wait=False)
    wait(500)
    drive.run(speed)
    wait(1500)
    drive.brake()
    wait(500)

    steer.run_target(1000, PARALLEL_STEER_CENTER, wait=False)
    wait(2000)
    drive.run(-speed)
    wait(1000)

    steer.run_target(1000, -sharp, wait=False)
    wait(500)
    drive.run(speed)
    wait(1500)
    drive.brake()
    wait(500)

    steer.run_target(1000, PARALLEL_STEER_CENTER, wait=False)
    wait(2000)

    hub.light.on(Color.GREEN)
    print("parallel park RIGHT done")


def parallel_park_left():
    speed = PARALLEL_SPEED
    sharp = PARALLEL_STEER_SHARP

    print("parallel park LEFT")
    hub.light.on(Color.BLUE)
    hub.speaker.beep(900, 150)

    steer.run_target(1000, sharp, wait=False)
    wait(500)
    drive.run(-speed)
    wait(2000)

    drive.brake()
    wait(500)
    steer.run_target(1000, -sharp, wait=False)
    wait(500)

    drive.run(speed)
    wait(3000)
    drive.brake()
    wait(500)

    steer.run_target(1000, PARALLEL_STEER_CENTER, wait=False)
    wait(3000)
    drive.run(-speed)
    wait(4000)
    drive.brake()
    wait(500)

    steer.run_target(1000, -sharp, wait=False)
    wait(1000)
    drive.run(-speed)
    wait(2500)
    drive.brake()
    wait(500)

    steer.run_target(1000, sharp, wait=False)
    wait(500)
    drive.run(speed)
    wait(1500)
    drive.brake()
    wait(500)

    steer.run_target(1000, PARALLEL_STEER_CENTER, wait=False)
    wait(2000)
    drive.run(-speed)
    wait(1000)

    steer.run_target(1000, sharp, wait=False)
    wait(500)
    drive.run(speed)
    wait(1500)
    drive.brake()
    wait(500)

    steer.run_target(1000, PARALLEL_STEER_CENTER, wait=False)
    wait(2000)

    hub.light.on(Color.GREEN)
    print("parallel park LEFT done")


def scan_for_parking():
    print("scan_for_parking: creeping, watching for bay...")
    hub.light.on(Color.MAGENTA)
    hub.speaker.beep(600, 200)

    right_buf = []
    left_buf  = []

    timeout = StopWatch()
    SCAN_TIMEOUT_MS = 10000

    while timeout.time() < SCAN_TIMEOUT_MS:
        _, _, _, d_left, d_right = read_cam()

        if d_right <= 0 or d_right >= 9000: d_right = 9999
        if d_left  <= 0 or d_left  >= 9000: d_left  = 9999

        if d_right < 9000:
            right_buf.append(d_right)
            if len(right_buf) > PARK_BASELINE_SAMPLES:
                right_buf.pop(0)

        if d_left < 9000:
            left_buf.append(d_left)
            if len(left_buf) > PARK_BASELINE_SAMPLES:
                left_buf.pop(0)

        if len(right_buf) >= PARK_BASELINE_SAMPLES:
            r_base = sum(right_buf[:-1]) / (PARK_BASELINE_SAMPLES - 1)
            r_curr = right_buf[-1]
            if r_curr > r_base + PARK_SPIKE_THRESHOLD:
                print("RIGHT bay detected! base:", r_base, "curr:", r_curr)
                drive.brake()
                wait(200)
                parallel_park_right()
                return

        if len(left_buf) >= PARK_BASELINE_SAMPLES:
            l_base = sum(left_buf[:-1]) / (PARK_BASELINE_SAMPLES - 1)
            l_curr = left_buf[-1]
            if l_curr > l_base + PARK_SPIKE_THRESHOLD:
                print("LEFT bay detected! base:", l_base, "curr:", l_curr)
                drive.brake()
                wait(200)
                parallel_park_left()
                return

        do_gyro()
        drive.dc(PARK_DETECT_SPEED)
        wait(10)

    drive.brake()
    steer.run_target(500, 0)
    print("scan_for_parking: timeout, no bay found")
    hub.light.on(Color.RED)


# ── startup gate ──────────────────────────────────────────────────────────────

if not fast_mode:
    parking_exit()
    hub.imu.reset_heading(0)
    wait(300)
    target = 0
    print("heading reset, starting race")
else:
    brake_on = True
    gyro_on  = True
    hub.imu.reset_heading(0)
    wait(300)
    target = 0
    print("fast mode, skipping parking")

# ── main loop ─────────────────────────────────────────────────────────────────

while True:

    hsv = color.hsv()
    ref = color.reflection()
    h, s, v = hsv.h, hsv.s, hsv.v

    _, cw, cid, d_left, d_right = read_cam()
    df = front_dist()

    # emergency brake — obstacle mode only
    if not fast_mode and brake_on and df < ULTRA_FRONT_MM:
        print("front sensor:", df, "mm — braking")
        emergency_stop()
        continue

    # obstacle avoidance via camera
    if cid in (1, 2) and cw >= CAM_MIN_WIDTH:
        if avoid_state == AVOID_NONE:
            avoid_dir = 1 if cid == 1 else -1
            print("obstacle id:", cid, "w:", cw)
        avoid_state = AVOID_ACTIVE
        avoid_off   = CAM_HEADING_OFFSET * avoid_dir
        hub.light.on(Color.RED if cid == 1 else Color.GREEN)

    elif cid in (1, 2) and cw < CAM_MIN_WIDTH:
        pass

    elif avoid_state == AVOID_ACTIVE:
        avoid_state = AVOID_HOLDING
        hold_tmr.reset()
        hub.light.on(Color.YELLOW)
        print("cleared, holding...")

    elif avoid_state == AVOID_HOLDING:
        if hold_tmr.time() >= HOLD_TIME:
            avoid_state = AVOID_RETURNING
            avoid_off   = -CAM_HEADING_OFFSET * avoid_dir
            return_tmr.reset()
            hub.light.on(Color.WHITE)
            print("returning...")

    elif avoid_state == AVOID_RETURNING:
        if return_tmr.time() >= RETURN_TIME:
            avoid_state = AVOID_NONE
            avoid_off   = 0
            avoid_dir   = 0
            hub.light.on(Color.GREEN)
            print("clear!")

    else:
        avoid_off = 0

    wall_follow(d_left, d_right)
    do_gyro()
    drive.dc(spd())

    if on_line and cooldown_tmr.time() > COOLDOWN_MS:
        on_line = False

    if not on_line:
        if is_blue(h, s, v, ref) and direction in (0, 1):
            on_line = True
            cooldown_tmr.reset()
            do_turn('blue')
        elif is_orange(h, s, v, ref) and direction in (0, 2):
            on_line = True
            cooldown_tmr.reset()
            do_turn('orange')

    if lap_lines >= LINES_TO_STOP:
        break

    wait(10)

# ── post-race ─────────────────────────────────────────────────────────────────

drive.brake()
steer.run_target(1000, 0)

# parallel parking — obstacle mode only, triggered by lateral ultrasonic spike
if not fast_mode:
    print("race done — entering parking scan")
    gyro_on = True
    scan_for_parking()

hub.light.on(Color.GREEN)
for _ in range(3):
    hub.speaker.beep(1000, 300)
    wait(400)

print("done!", TOTAL_LAPS, "laps |", "fast" if fast_mode else "obstacle", "mode")

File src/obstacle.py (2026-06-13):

from pybricks.hubs import PrimeHub
from pybricks.pupdevices import Motor, ColorSensor, UltrasonicSensor
from pybricks.parameters import Color, Port
from pybricks.tools import wait, StopWatch
from pupremote_hub import PUPRemoteHub

hub   = PrimeHub()
steer = Motor(Port.A)
drive = Motor(Port.C)
color = ColorSensor(Port.E)
ultra = UltrasonicSensor(Port.D)

drive.control.limits(acceleration=20000)
steer.control.limits(acceleration=20000)

# ╔══════════════════════════════════════════════════════════════════════════════╗
# ║                        TUNABLE CONSTANTS                                   ║
# ╚══════════════════════════════════════════════════════════════════════════════╝

# ── SPEED ──────────────────────────────────────────────────────────────────────

SPEED = 40   # Driving speed (dc%)

# ── GYRO / STEERING CORRECTION ────────────────────────────────────────────────

KP           = 2.0   # Heading error multiplier
KR           = 0.3   # Angular rate dampener
STEER_CENTER = 0     # Straight-ahead steer angle (degrees)
STEER_LIMIT  = 60    # Maximum steer angle allowed (degrees)

# ── TURNS: wait-for-wall + reverse ────────────────────────────────────────────

TURN_STEER          = 60    # Full lock steer angle for reverse turn (degrees)
WALL_TURN_MM        = 100   # Front wall distance that fires the turn (mm)
REVERSE_MS          = 2500  # Duration of reverse during turn (ms)
WALL_TAP_REVERSE_MS = 500   # Reverse duration each time wall is hit while waiting (ms)

# ── LAPS ───────────────────────────────────────────────────────────────────────

TOTAL_LAPS    = 3
LINES_TO_STOP = TOTAL_LAPS * 4   # 4 lines per lap
COOLDOWN_MS   = 1500              # ms cooldown after each line crossing

# ── COLOR THRESHOLDS: BLUE LINE ───────────────────────────────────────────────

BLUE_H_MIN = 205;  BLUE_H_MAX = 230
BLUE_S_MIN = 65;   BLUE_S_MAX = 95
BLUE_V_MIN = 35;   BLUE_V_MAX = 65
BLUE_REF_MIN = 15; BLUE_REF_MAX = 35

# ── COLOR THRESHOLDS: ORANGE LINE ─────────────────────────────────────────────

ORANGE_H_MIN = 335; ORANGE_H_MAX = 15
ORANGE_S_MIN = 35;  ORANGE_S_MAX = 80
ORANGE_V_MIN = 45;  ORANGE_V_MAX = 80
ORANGE_REF_MIN = 25; ORANGE_REF_MAX = 50

# ── HUSKYLENS PILLAR COLOR ID RANGES ──────────────────────────────────────────
# IDs 1–5  → GREEN pillar → robot dodges LEFT
# IDs 6–10 → RED   pillar → robot dodges RIGHT

GREEN_ID_MIN = 1;  GREEN_ID_MAX = 5
RED_ID_MIN   = 6;  RED_ID_MAX   = 10

# ── OBSTACLE DODGE ────────────────────────────────────────────────────────────

DODGE_CY_START  = 30    # cy where ramp begins (pillar far away)
DODGE_CY_FULL   = 160   # cy where full offset is reached (pillar close)
DODGE_SNAP_CY   = 100   # cy threshold for instant full dodge on first sight
DODGE_MAX_OFF   = 35    # Maximum dodge heading offset (degrees)
DODGE_HOLD_MS   = 700   # Hold time after pillar clears frame (ms)
DODGE_RETURN_MS = 600   # Blend-back time after hold (ms)

# ── COUNTER-STEER ─────────────────────────────────────────────────────────────

COUNTER_OFF_RED   = -25   # Left snap after red dodge (degrees)
COUNTER_OFF_GREEN =  30   # Right snap after green dodge (degrees)
COUNTER_HOLD_MS   = 400   # Hold duration (ms)
COUNTER_BLEND_MS  = 300   # Fade duration (ms)

# ── EMERGENCY BRAKE ───────────────────────────────────────────────────────────

ULTRA_FRONT_MM   = 120   # Front distance that triggers emergency stop (mm)
ULTRA_REVERSE_MS = 1500  # Reverse duration after emergency stop (ms)
BLIND_MS         = 1500  # Camera blackout window after emergency stop (ms)

# ── WALL SAFETY NUDGE ─────────────────────────────────────────────────────────

OBS_WALL_MIN_MM  = 150   # Side distance that triggers wall nudge (mm)
OBS_WALL_MAX_OFF = 8     # Heading offset applied by wall nudge (degrees)

# ── STARTUP STRAIGHT ──────────────────────────────────────────────────────────

PARK_EXIT_STEER_ANGLE = -80   # Hard steer angle during exit (degrees; negative = left)
PARK_EXIT_STEER_MS    = 1000  # Time to hold steer before driving (ms)
PARK_EXIT_DRIVE_SPEED =   50  # Drive speed during exit (dc%)
PARK_EXIT_DRIVE_MS    = 1500  # How long to drive forward out of bay (ms)
PARK_EXIT_STRAIGHT_MS = 1000  # How long to gyro-straight after exit (ms)

# ── AVOID STATES ───────────────────────────────────────────────────────────────

AVOID_NONE      = 0
AVOID_ACTIVE    = 1
AVOID_HOLDING   = 2
AVOID_RETURNING = 3
AVOID_COUNTER   = 4

# ── STATE VARS ─────────────────────────────────────────────────────────────────

target      = 0
direction   = 0
lap_lines   = 0
on_line     = False
gyro_on     = False
brake_on    = False

avoid_state = AVOID_NONE
avoid_dir   = 0
avoid_off   = 0
wall_off    = 0

cam_blind  = False
blind_tmr  = StopWatch()

hold_tmr     = StopWatch()
return_tmr   = StopWatch()
counter_tmr  = StopWatch()
cooldown_tmr = StopWatch()
loop_tmr     = StopWatch()

# ── BOOT ───────────────────────────────────────────────────────────────────────

steer.run_target(1000, 0)
hub.light.on(Color.YELLOW)
print("booting...")
wait(2000)

print("starting ESP32...")
lms = PUPRemoteHub(Port.B)
lms.add_channel('hl', 'hhhhhh')
wait(1500)

print("ready  laps:", TOTAL_LAPS, "lines:", LINES_TO_STOP)
hub.light.on(Color.GREEN)
hub.speaker.beep(1000, 100)
hub.speaker.beep(1200, 100)

# ── HELPERS ────────────────────────────────────────────────────────────────────

def front_dist():
    try:
        d = ultra.distance()
        return d if d else 9999
    except:
        return 9999

def read_cam():
    try:
        cx, cy, cw, cid, dl, dr = lms.call('hl')
        return (cx, cy, cw, 0, cid,
                dl if dl > 0 else 9999,
                dr if dr > 0 else 9999)
    except:
        return 0, 0, 0, 0, 0, 9999, 9999

def do_gyro():
    if not gyro_on:
        return
    total_off = avoid_off + wall_off
    err  = hub.imu.heading() - (target + total_off)
    rate = hub.imu.angular_velocity()[2]
    cor  = max(-STEER_LIMIT, min(STEER_LIMIT, KP * err - KR * rate))
    steer.run_target(1000, int(STEER_CENTER + cor), wait=False)

def is_green_block(cid):
    return GREEN_ID_MIN <= cid <= GREEN_ID_MAX

def is_red_block(cid):
    return RED_ID_MIN <= cid <= RED_ID_MAX

def is_any_block(cid):
    return is_green_block(cid) or is_red_block(cid)

def dodge_dir_from_cid(cid):
    return -1 if is_green_block(cid) else 1

def is_blue(h, s, v, ref):
    return BLUE_H_MIN <= h <= BLUE_H_MAX \
       and BLUE_S_MIN <= s <= BLUE_S_MAX \
       and BLUE_V_MIN <= v <= BLUE_V_MAX \
       and BLUE_REF_MIN <= ref <= BLUE_REF_MAX

def is_orange(h, s, v, ref):
    return (h >= ORANGE_H_MIN or h <= ORANGE_H_MAX) \
       and ORANGE_S_MIN <= s <= ORANGE_S_MAX \
       and ORANGE_V_MIN <= v <= ORANGE_V_MAX \
       and ORANGE_REF_MIN <= ref <= ORANGE_REF_MAX

def compute_dodge_off(cy):
    if cy <= DODGE_CY_START:
        return 0
    if cy >= DODGE_CY_FULL:
        return DODGE_MAX_OFF
    return DODGE_MAX_OFF * (cy - DODGE_CY_START) // (DODGE_CY_FULL - DODGE_CY_START)
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
